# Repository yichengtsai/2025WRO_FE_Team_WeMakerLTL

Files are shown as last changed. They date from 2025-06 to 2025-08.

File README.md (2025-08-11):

# WRO 2025 未來工程師 - WeMaker-LTL

## 隊伍資訊

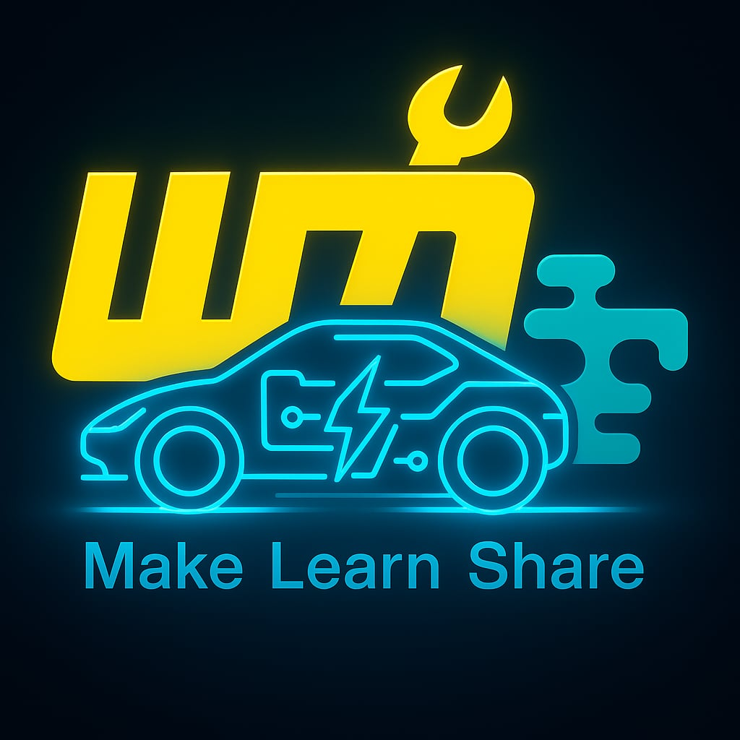
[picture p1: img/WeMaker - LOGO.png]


- **隊伍名稱**： WeMaker-LTL
- **隊員**： 蔡宜成、林仲斌、賴孟承
- **教練**： 楊智仁
- **學校/組織**： TCIVS WeMaker FabLab

## 評分對照表
為方便 WRO 2025 評審快速找到對應文件，以下為附件 C 的 7 項評分標準與相關檔案的對照表：
1. 移動性管理: [/docs/engineering_report.md](docs/engineering_report.md#移動性管理)
2. 電源和感測器:[/docs/engineering_report.md](docs/engineering_report.md#電源管理與感測)
3. 障礙物管理:[/docs/engineering_report.md](docs/engineering_report.md#障礙管理)
4. 圖片-團隊和汽車: [/media/README.md](media/README.md)
5. 完整的影片: [/media/README.md#demonstration-videos](media/README.md#demonstration-videos)
6. 使用GitHub: [/README.md](README.md)
7. 工程因素/技術條件: [/hardware/part_files](/hardware/part_files.md)
8. 評審總體印象: [/README.md/快速開始](README.md#快速開始)

## 快速開始
以下步驟幫助您快速設置並重現我們的專案成果，適用於其他隊伍、開發者或感興趣的使用者。

### 先決條件
- **硬體**：
  - Raspberry Pi 4B (8GB RAM)
  - JGA25-370 直流馬達 (x2) 與 L298N 馬達驅動模組
  - MG90 伺服馬達 (轉向)
  - TCS34725 顏色感測器
  - IMX477 攝影機模組
  - LDRobot D100 LiDAR
  - Adafruit BNO055 IMU
  - 底盤：雷射切割木板、3D 列印支架、LEGO 差速器與輪胎
- **工具**：雷射切割機、3D 印表機、螺絲起子、焊接工具
- **軟體**：Raspberry Pi OS、Python 3、Git、OpenCV、ROS

### 設置步驟
1. **組裝硬體**：
   - 參考 `hardware/circuit.md` 連接電路。
   - 使用 `docs/hardware` 中的 STL 檔案列印感測器與馬達支架。
   - 組裝底盤，確保阿克曼轉向系統（80% 阿克曼率）正確設置。
2. **設置軟體環境**：

   ```bash
   # Clone this repository
   git clone https://github.com/yichengtsai/2025WRO_FE_Team_WeMakerLTL.git
   cd WRO-2025-Future-Engineers-TeamName

   # Copy the image file to the SD card
   Use balenaEtcher copy the operating system to the SD card.
   Link: https://etcher.balena.io/
   ```
3. **配置參數**：
   - 檢查 `src/config/hardware_config.md` 中的硬體引腳與感測器設定，根據您的硬體調整。
4. **執行程式**：
   ```bash
   python src/test.py
   ```
   - 確保 Raspberry Pi 已連接到所有設備。
   - 將機器人放置於場地內，觀察其移動表現。
5. **驗證結果**：
   - 運行 `src/OpenChallenge.py` 與 `src/ObstacleChallenge.py` 檢查模組功能。
   - 參考 [media/README.md Demonstration Videos](media/README.md#demonstration-videos) 對比您的機器人表現。

### 預期成果
- 機器人應能自主在比賽場地內繞行三圈後停止，平均完成時間 60 秒。
- 機器人從停車區域出發，繞行三圈後自組移動到停車區域內，並且平行停進停車格內，平均完成時間 120 秒。

如需詳細說明，請參閱 `docs/engineering_report.md`。

## 硬體架構
- **主控制器**：Raspberry Pi 4B (8GB RAM)，負責處理感測器數據與執行導航演算法。
- **驅動馬達**：JGA25-370 直流馬達，提供差速驅動動力。
- **馬達驅動模組**：L298N，控制 JGA25-370 馬達的速度與方向。
- **轉向馬達**：MG90 伺服馬達，實現精確的阿克曼轉向控制（80% 阿克曼率）。
- **顏色感測器**：TCS34725，用於檢測賽道標記與顏色變化。
- **影像模組**：IMX477 高解析度攝影機，支援視覺導航與障礙辨識。
- **光達**：LDRobot D100 LiDAR，提供 360° 環境掃描與距離測量。
- **慣性測量單元 (IMU)**：Adafruit BNO055，追蹤機器人姿態與方向。
- **底盤**：雷射切割木板搭配 3D 列印支架，結合 LEGO 差速器與輪胎，確保結構穩固與靈活移動。
- **轉向系統**：阿克曼轉向系統（80% 阿克曼率），優化賽道轉彎性能。

詳細硬體設計請參閱 `/hardware/` 中的電路圖、照片與 3D 模型。

## 軟體架構
- **程式語言**：Python 3.8+，運行於 Raspberry Pi 4B。
- **模組化設計**：
  - **感測器與執行器模組** (`src/function.py`)：處理 TCS34725、LDRobot D100、BNO055的數據以及控制JGA25-370 馬達、L298N 驅動器 與 MG90 伺服馬達。
- **核心演算法**：
  - **路徑規劃**：在閃避積木的應用中，是根據積木在影像中的位置，計算出適當的轉向角度，並傳送至伺服馬達控制避開動作。該策略不使用傳統意義上的全區域規劃演算法，而是根據即時畫面中的積木位置做出本地性的轉向調整。
  - **障礙迴避**：為了讓車輛能順利繞過紅色與綠色積木，我們設計了一套簡單有效的閃避方法。當攝影機偵測到畫面中出現積木時，系統會判斷它的位置和面積，確認是否需要進行閃避動作。
  然後會根據積木的偏移程度和遠近調整轉向角度，並將這個角度轉換成伺服馬達的控制指令，讓車子能及時且順暢地避開障礙物。
  - **賽道辨識**：在場地中，地面設有藍色與橘色的標線作為定位依據。由於這兩條線間距接近，當顏色感測器偵測到任何一條時，通常代表車輛已進入彎道區域。
  為確保車輛能順利通過彎道，除了顏色判斷外，我們同步結合陀螺儀的角度資訊，控制車輛轉向的程度與穩定性。當進入轉彎時，系統會根據目前的角度進行角度補償與動作調整，並控制車輛以預定角度平滑轉彎，避免偏離路徑。

- **ROS 系統應用（LiDAR 專用）** :

   - 在本專案中，ROS 僅用於處理 LDRobot D100 LiDAR 的資料，其他感測器與控制則直接由 Python 模組處理。使用 ROS (Robot Operating System) 作為 LiDAR 資料的中介層，原因是 ROS 擁有豐富的感測器驅動支援，能快速整合 LDRobot D100 LiDAR。

   - **啟動方式**：透過 ROS 套件 ldlidar 啟動 LiDAR 節-點。

   - **資料流**：LiDAR 節點以 /scan topic 發布雷射掃描數據，Python 主控程式透過 rospy 訂閱該 topic 並進行距離與角度分析。

   - **用途**：用於比賽中的車道置中與障礙物偵測，提升機器人在動態環境中的反應速度。

詳見 `src/` 中的程式碼與模組說明。

## 儲存庫結構
- **docs/**：
  - `engineering_report.md`:完整的工程報告，涵蓋設計、開發與測試。
  - `testing.md`:測試計劃、結果與影片，展示機器人性能。
- **hardware/**：
  - `part_files.md`:硬體圖檔說明。
  - `circuit.md`:電路圖說明。
- **src/**：
  - `ObstacleChallenge.py`:障礙挑戰賽程式碼，執行避障、影像辨識、...。
  - `OpenChallenge.py`:資格賽程式碼，執行光達車輛置中，...。
  - `test.py`:單元測試程式碼，執行車輛周邊設備掃描與驗證設備正常工作。
- **requirements.txt**: Python依賴項清單。
- **LICENSE**:專案授權(MIT)。
- **CHANGELOG.md**:記錄專案更新的重大變更日誌。

## 安裝與執行
### 環境設置
1. **硬體準備**：
   - 確保所有硬體（Raspberry Pi 4B、JGA25-370、L298N 等）正確連接，參考 `/hardware/Circuit.md`。
   - 安裝 3D 列印零件，參考 `/hardware/part_files`。
2. **軟體環境**：
   ```bash
   # 複製儲存庫
   git clone https://github.com/yichengtsai/2025WRO_FE_Team_WeMakerLTL.git

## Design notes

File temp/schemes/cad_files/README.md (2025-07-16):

## CAD Files
* You can download or use these 2D/3D files by yourself. (For teaching purposes only)

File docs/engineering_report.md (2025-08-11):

# Engineering Report

# 移動性管理

## 底盤

### 驅動系統

### 馬達控制板
#### L298N
- IC 型號	L298N 雙 H 橋馬達驅動 IC
- 驅動電壓	5V ~ 35V（邏輯電壓 5V）
- 邏輯電壓	5V（模組可內建穩壓器）
- 最大輸出電流	2A / 每通道（瞬間最大可達 3A）
- 驅動通道數	2 通道（可驅動兩個直流馬達或一個雙極步進馬達）
- 控制方式	數位訊號控制（IN1 ~ IN4）、PWM 調速
- 支援功能	正轉、反轉、剎車、停止、PWM 調速
- 功耗	依負載與驅動電壓而異
- 模組接腳說明：
    - 接腳	功能
    - IN1 / IN2	控制馬達A方向
    - IN3 / IN4	控制馬達B方向
    - ENA / ENB	啟用並調速（通常接 PWM）
    - OUT1 / OUT2	馬達A輸出
    - OUT3 / OUT4	馬達B輸出
    - VCC	馬達電源（5V ~ 35V）
    - GND	接地
    - 5V	模組內部邏輯電壓輸出/輸入（若使用板上穩壓器，插跳線帽以供應5V）
<div align="center">
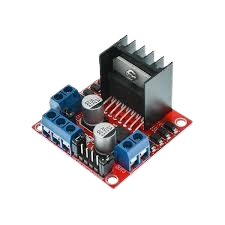
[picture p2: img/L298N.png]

</div>

#### 後輪直流馬達

在後輪驅動部分使用一顆130RPM 的直流馬達（DC Motor）作為動力來源。直流馬達具有轉速穩定、控制方式簡單的特性。本系統透過金屬齒輪組將馬達輸出連接至變速器，以調整扭力與轉速的傳遞效率，使車輛具備良好的啟動能力與穩定的行進速度。金屬齒輪具有良好的強度與耐磨性，可提升整體傳動系統的壽命與可靠度。

- 優點
  - 控制簡單，可透過 PWM 輕鬆調整速度
  - 可提供穩定扭力，適合驅動車輪
  - 搭配金屬齒輪與變速機構，提升扭力輸出並延長使用壽命
  - 兼具穩定推進與反應速度

<div align="center">
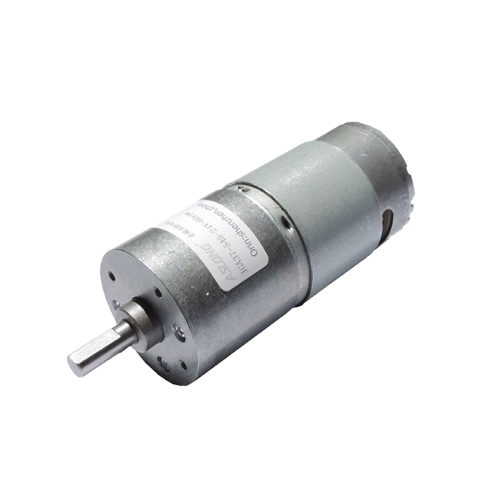
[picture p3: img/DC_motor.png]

</div>

#### 變速機構

我們考慮使用差速器結構作為後輪驅動的變速機構之一。差速器是一種可以同時傳遞動力與允許左右車輪轉速不同的機構，常用於汽車後輪驅動系統中。當車輛直線行駛時，兩側輪子等速旋轉；當轉彎時，內外側輪子轉速不同，差速器內部的行星齒輪則會自動補償兩側轉速差，維持動力平衡並減少輪胎摩擦。

圖 1（左圖）| 展示車輛直行時的差速器狀態，左右輪轉速一致，綠色中間齒輪不轉。

圖 2（右圖）| 展示車輛轉彎時的狀態，一側輪子轉速下降，差速器內部齒輪開始旋轉來補償另一側輪子的加速。

<p align="center">
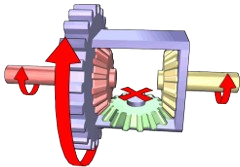
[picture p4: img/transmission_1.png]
圖1
  
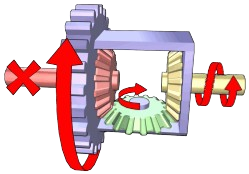
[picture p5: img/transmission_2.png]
圖2
  
</p>
<p align="center"><b>圖 1（左）：直行狀態  圖 2（右）：轉彎補償</b></p>

<div align="center">
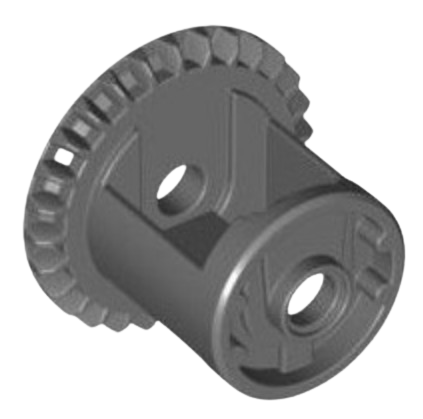
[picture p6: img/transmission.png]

</div>
<div align="center">樂高變速器</div>

### 轉向系統
#### Ackermann Steering Mechanism (阿克曼轉向機構介紹)

本設計採用了 **阿克曼轉向機構（Ackermann Steering Mechanism）** 作為前輪轉向方案。該機構透過幾何設計，使車輛在轉彎時前輪能指向同一圓心，內外輪轉向角度不同，符合理想轉彎軌跡。這種設計常見於真實汽車中，能有效提升轉彎穩定性與轉向效率。本車輛的阿克曼機構由光固化3D列印製作，搭配伺服馬達驅動，實現準確且穩定的轉向控制。
- 優點
  - 減少輪胎在轉彎時的滑移與磨損
  - 提高轉彎的穩定性與效率
  - 模擬真實車輛的轉向行為，提升真實感與控制精度
  - 可與伺服馬達整合，實現精準轉角控制

<div align="center">
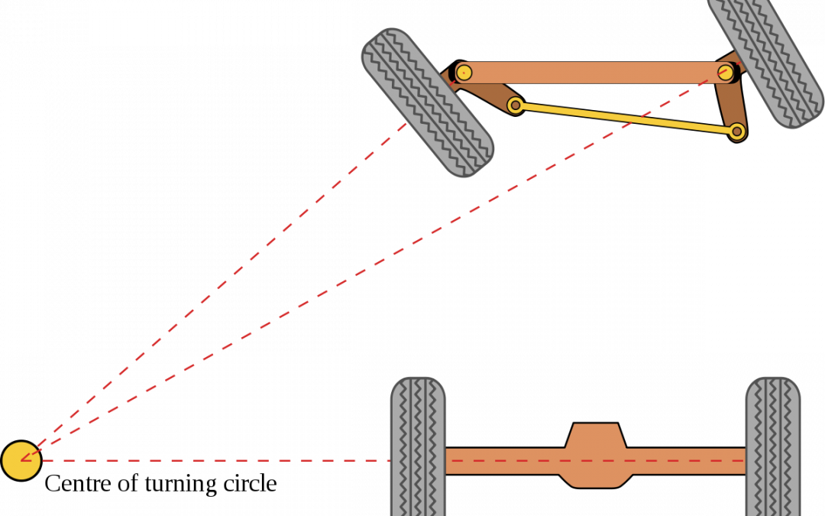
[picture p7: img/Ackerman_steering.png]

</div>
<div align="center">阿克曼轉向機構</div>

### 伺服馬達
#### MG90
- 工作電壓	4.8 V ～ 6.0 V
- 扭力	約 1.8 kg·cm（4.8 V）
約 2.2 kg·cm（6.0 V）
- 速度	約 0.1 秒 / 60°（4.8 V）
- 工作電流	空載約 100 mA，負載時更高
- 控制方式	PWM 控制，頻率約 50 Hz
- 齒輪材質	金屬齒輪（鋼齒）
- 軸承類型	雙軸承設計，提高穩定性
- 角度範圍	約 180°
<div align="center">
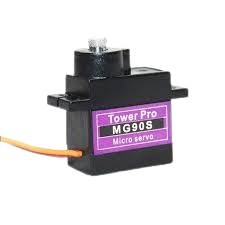
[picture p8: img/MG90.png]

</div>

# 電源管理與感測

## 電源(電池、降壓、每個模組供電方式)

### 電源系統概要圖
<div style="text-align: center;">
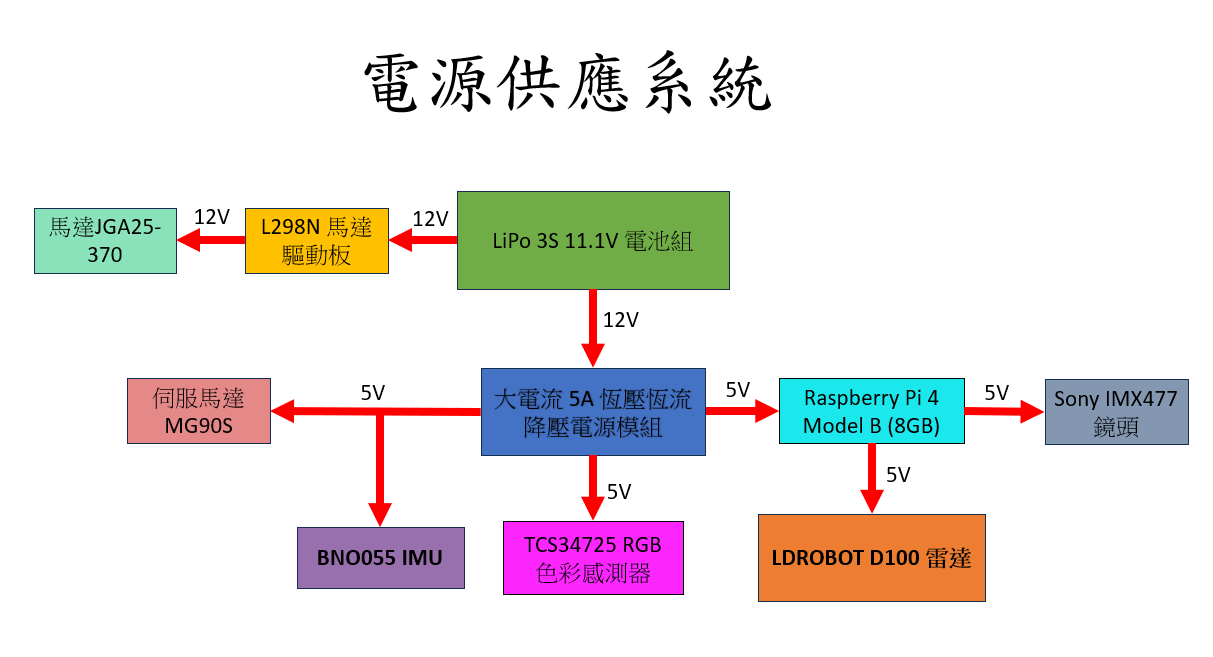
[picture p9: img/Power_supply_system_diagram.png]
電源供應系統
    
</div>

### 電池
原先我們採用 18650 鋰電池 作為電源供應，但由於樹莓派運作時需要穩定的 5V 電壓，而單顆 18650 電池的電壓範圍介於 4.2V 至 3.0V，即使透過升壓模組轉換，當電量下降過快時仍容易導致 電壓不穩，進而產生 系統重啟、螢幕閃爍，甚至在寫入過程中造成 SD 卡損壞 等問題。

為了解決上述問題，我們改採 LiPo 3S 11.1V 鋰聚合物電池 作為主要電源。雖然需要額外配置降壓模組來將電壓轉為穩定的 5V，但相較於單顆 18650 電池，其具有 更高的輸入電壓裕度與更穩定的電流輸出，能有效改善電壓不穩所帶來的風險，並提升系統運行的可靠性與安全性。

<div style="text-align: center;">
  <table>
    <tr>
      <th style="text-align: center;">18650充電電池</th>
      <th style="text-align: center;">LiPo 3S 11.1V 鋰聚合物電池</th>
    </tr>
    <tr>
      <td>
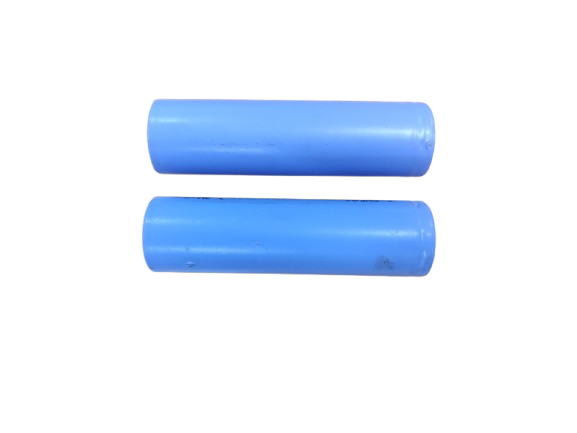
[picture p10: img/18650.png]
18650充電電池
        
      </td>
      <td>
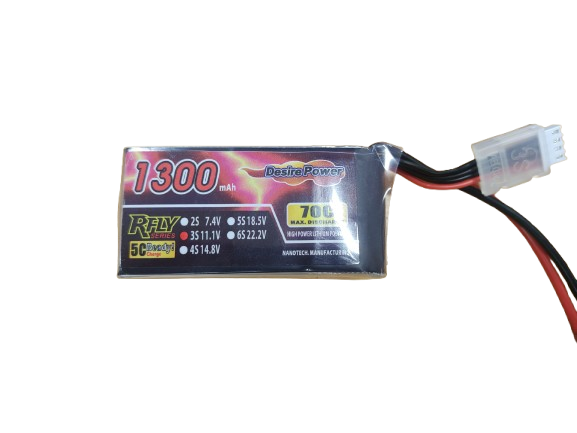
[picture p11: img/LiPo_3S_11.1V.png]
LiPo 3S 11.1V 鋰聚合物電池
        
      </td>
    </tr>
  </table>
</div>

### 降壓板
#### High Current 5A Constant Voltage Constant Current Buck Power Supply Module
- 輸入電壓	DC 4V ～ 38V（推薦 5V～36V）
- 輸出電壓	DC 1.25V ～ 36V（可調）
- 輸出電流	最大 5A（建議持續 4.5A 以下）
- 輸出功率	最大 75W（需加散熱片）
- 轉換效率	高達 96%（視輸入/輸出電壓與電流）
- 恆壓/恆流控制	可透過兩顆可調電位器分別設定輸出電壓與限流值
- 開關頻率	約 180kHz（視版本與晶片而定）
- 保護功能	輸出短路保護、過溫保護、過電流保護
<div align="center">
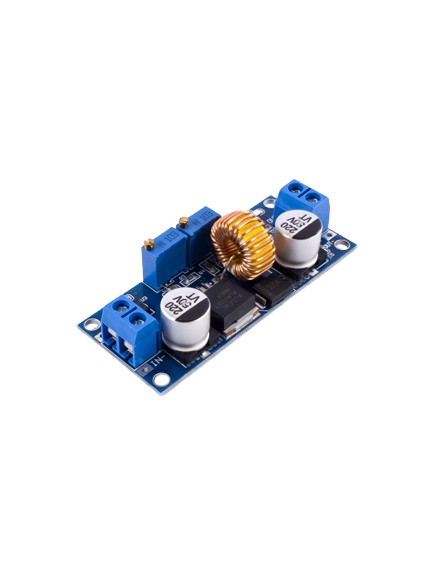
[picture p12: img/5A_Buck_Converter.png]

</div>

## 控制器
#### Raspbrry pi 4(8GB)
- 處理器 (CPU)
    - Broadcom BCM2711
    - 四核心 ARM Cortex-A72 (ARM v8) 64-bit 處理器
    - 時脈：1.5GHz
- 記憶體 (RAM)
    - 8GB LPDDR4 SDRAM
    - 記憶體與 SoC 整合在一個封裝上
- 圖形處理器 (GPU)
    - Broadcom VideoCore VI
    - 支援 OpenGL ES 3.0
- 輸出入埠 (I/O Ports)
    - 2 × USB 3.0
    - 2 × USB 2.0
    - 1 × Gigabit Ethernet (RJ45)
    - 40-pin GPIO header
    - CSI 相機介面
    - DSI 顯示介面
<div align="center">
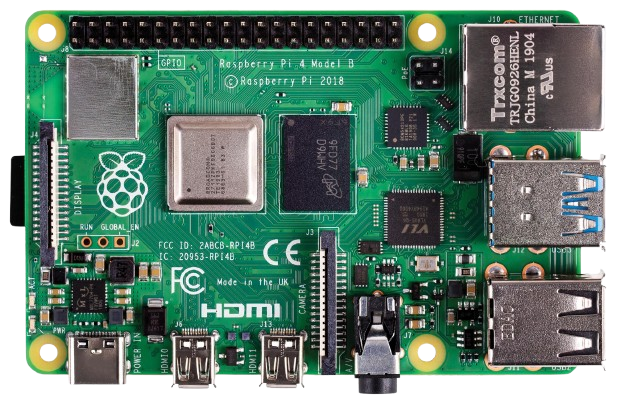
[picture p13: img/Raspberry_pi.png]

</div>

## 感測器
### 攝影鏡頭
#### Sony IMX477
- 感測器類型：CMOS（背照式，BSI）
- 解析度：12.3 Megapixels
- 感測器尺寸：1/2.3 英吋
- 像素大小：1.55μm × 1.55μm
- 有效畫素：4056 × 3040
- 輸出格式：
    - RAW Bayer（10-bit / 12-bit）
    - 支援 MIPI CSI-2 數位輸出
<div align="center">
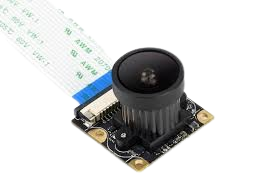
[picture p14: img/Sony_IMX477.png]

</div>

### 顏色感測器
#### TCS34725
- 感測元件類型RGB + Clear 光感測器
- 通訊介面I²C（最大 400 kHz）
- ADC 解析度16 位元（4 通道同步）
- 光感通道R（紅）、G（綠）、B（藍）、C（清光）
- 增益設定1x、4x、16x、60x
- 整合時間2.4 ms ~ 700 ms（可程式化）
- 紅外線濾光片內建，可提升色彩準確度
- 工作電壓2.7V ~ 3.6V（模組通常支援 3.3V / 5V）
- 輸出資料格式每通道 16 位元數值（R、G、B、C）
<div align="center">
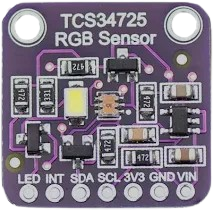
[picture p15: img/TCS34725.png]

</div>

### 光學雷達
#### LDROBOT D100 LiDAR
- 測距原理	Triangulation（CCD 三角測量）
- 掃描範圍	360° 全方位旋轉
- 測距範圍	0.15 ～ 8 公尺
- 角度解析度	約 1°
- 資料輸出頻率	約 2300 點/秒
- 掃描頻率	6 Hz（固定）
- 測距精度	±3 cm（典型值）
- 通訊介面	UART（3.3V TTL）
- 供電電壓	DC 5V（USB 或 UART）
<div align="center">
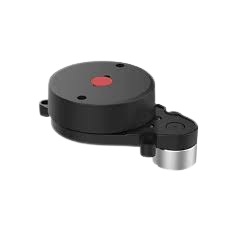
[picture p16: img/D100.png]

</div>

### 陀螺儀
#### BNO055 IMU
- 感測器內容	三軸加速度計 + 三軸陀螺儀 + 三軸磁力計 + 32-bit Cortex-M0F FUSION MCU
- 輸出數據	Quaternion（四元數）、Euler 角（Yaw, Pitch, Roll）、加速度、角速度、磁場、線性加速度、重力向量等
- 加速度範圍	±2g / ±4g / ±8g / ±16g
- 陀螺儀範圍	±125 / ±250 / ±500 / ±1000 / ±2000 dps
- 磁力計範圍	±1300 μT（X/Y 軸）、±2500 μT（Z 軸）
- 取樣率（輸出率）	最多 100 Hz（視模式）
- 絕對方向誤差	約 ±2.5°（典型值）
- 電壓需求	3.0V ~ 3.6V（模組常含穩壓可支援 3.3V / 5V）
- 通訊介面	I²C（100kHz～400kHz）與 UART（最大460800 bps）
- 內建演算法	Bosch Sensor Fusion Algorithm（可直接輸出姿態角）
<div align="center">
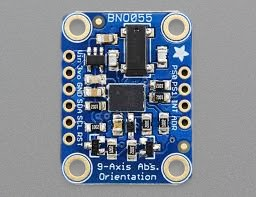
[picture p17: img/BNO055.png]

</div>

# 障礙管理

## 資格賽

### 功能概述
我們透過整合陀螺儀與光達，實現車子在限定空間內的繞圈移動行為。整體動作流程分為以下步驟：

一、初始化階段
啟動系統後，進行感測器初始化與通訊設定，同步讀取陀螺儀、光達與光感的資料，並透過光達資料進行初始位置的置中校正。

二、前進與距離判斷
車子向前行駛，光達持續檢測前方牆壁距離，當偵測到接近指定距離時，觸發轉彎程序。

三、轉彎動作
根據當前角度與預設目標角度，控制車子執行陀螺儀角度旋轉。旋轉完成後，再次透過光達執行橫向置中校正。

四、重複流程
校正完成後進入下一段直行流程，如此循環構成完整繞圈動作。

<div align="center">
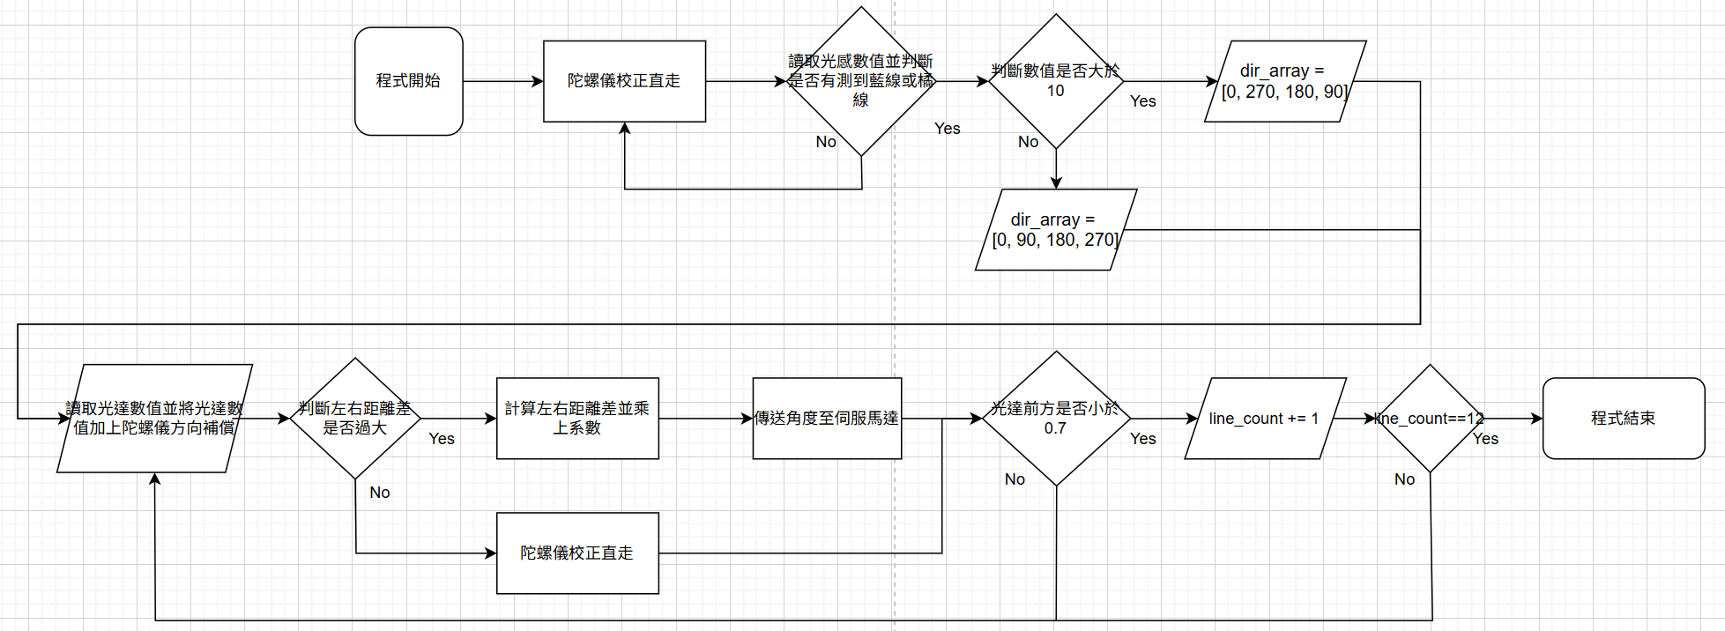
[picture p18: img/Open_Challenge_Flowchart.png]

</div>

### 光達置中校正運算

#### 補償原理:

一、角度轉換與投影修正

假設車身偏轉角度為 gyro（單位：度），轉換為弧度後，將原始距離乘上 cos(gyro)，修正光達讀值的投影誤差。
原因在於：當車身偏轉時，光達實際測得的是與牆面夾角方向的距離，其垂直距離需透過餘弦關係還原。

公式：
```
corrected_left  = left  × cos(gyro)
corrected_right = right × cos(gyro)
```
二、額外補償微調（角度漂移影響）

為進一步提升精度，對左右距離加入一項與角度成比例的補償量 angle_compensation = abs(gyro) × 0.005，模擬由於傾斜造成的視角偏移。

根據偏轉方向，左右距離分別加減該補償量：
```
if gyro > 0:
    corrected_left  -= angle_compensation
    corrected_right += angle_compensation
else if gyro < 0:
    corrected_left  += angle_compensation
    corrected_right -= angle_compensation
```

## 障礙挑戰賽

### 功能概述

本系統為一套即時影像與感測器融合的避障控制機制，主要針對車子在移動過程中自動偵測前方障礙物（牆體與積木），並根據當前車身姿態動態調整避讓路徑。系統透過攝影機進行目標輪廓偵測，獲取障礙物位置，並結合陀螺儀輸出的車身旋轉角度進行座標補償，以修正因鏡頭畸變與車身姿態變化造成的誤差。
在避障邏輯中，系統會先根據車頭與目標物位置計算斜率，映射為伺服馬達轉向角度，生成基礎避讓方向；同時，系統會預測此路徑是否可能與牆體相交，若偵測到潛在碰撞，則計算交點位置並動態修正避讓方向，確保車輛在保持安全距離的前提下順利繞過障礙物。

<div align="center">
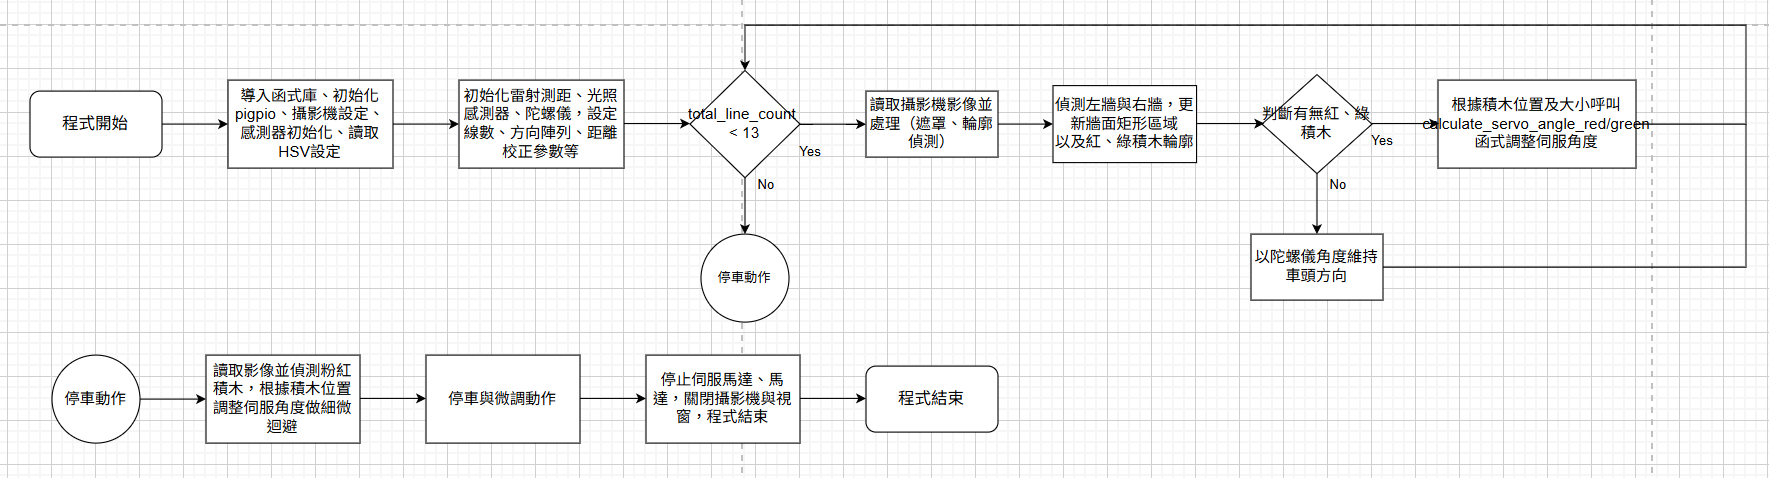
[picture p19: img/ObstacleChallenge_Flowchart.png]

</div>

### 顏色遮罩設定與輪廓擷取

為了辨識場地中的紅色與綠色積木，程式採用了 HSV 色彩空間來進行顏色篩選。與 RGB 不同，HSV 更適合處理顏色辨識的問題，因為它將顏色（Hue）、飽和度（Saturation）與明亮度（Value）分離，能更穩定地適應不同光照條件。

<div align="center">
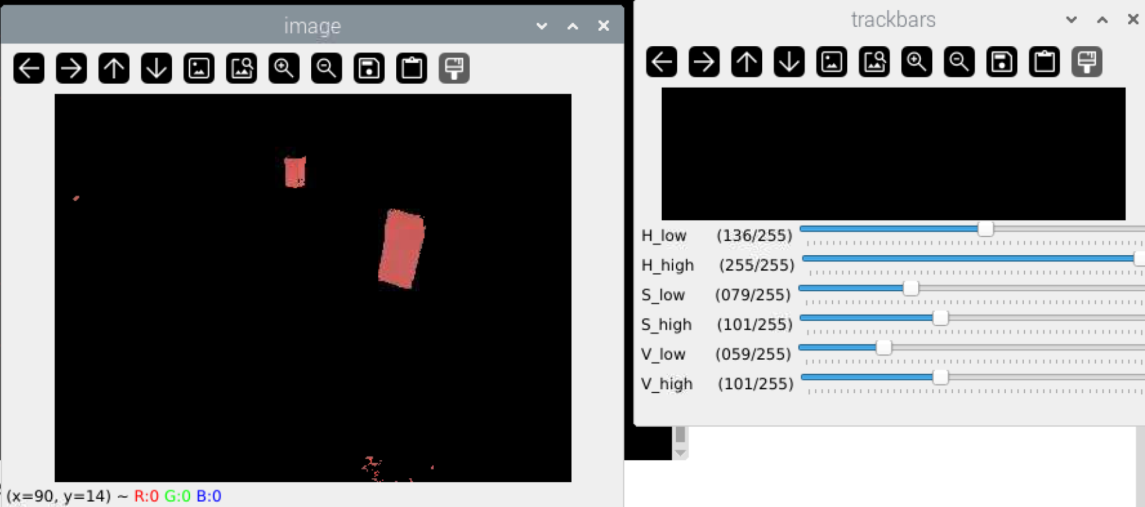
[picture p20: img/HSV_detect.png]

</div>

使用 ``` cv2.inRange ``` 函式可以將在範圍內的像素轉為白色（255），不在範圍內的轉為黑色（0），形成二值遮罩。再透過 cv2.findContours 找出輪廓，即可擷取紅綠積木在影像中的位置。這些輪廓後續會用來判斷積木位置與大小，進一步進行避障判斷與行為控制。

根據設定好的色彩範圍，對畫面進行遮罩，找出特定顏色積木的區域
```
green_mask = cv2.inRange(hsv, green_lower, green_upper)
contours, _ = cv2.findContours(green_mask, cv2.RETR_EXTERNAL, cv2.CHAIN_APPROX_SIMPLE)
```

### 物件偵測及位置取得

系統透過影像處理（OpenCV）對畫面中的紅色牆或積木進行輪廓偵測。
為了後續避障，需要獲取該物件的矩形邊界座標 (x, y, w, h) 及其底部 y 座標 y_bottom，並找出距離車輛最近的目標。
```
for cnt in red_contours:
    area = cv2.contourArea(cnt)
    if area > 50:
        x, y, w, h = cv2.boundingRect(cnt)
        cv2.rectangle(imageFrame, (x, y), (x + w, y + h), (0, 0, 255), 2)
         y_bottom = y + h
        if y_bottom > max_y_bottom_red:
            max_y_bottom_red = y_bottom
            closest_tx_red = x + w + 100 + int(abs(gyro)*0.15)
            closest_ty_red = y
```

### 陀螺儀補償

由於攝影機鏡頭存在一定的畸變（廣角或桶狀變形），車輛在旋轉時，物體的投影位置會產生偏移，導致直接從影像計算的避障角度不準確。
為修正此誤差，將車輛的實際旋轉角度（由陀螺儀讀取）乘以一個比例係數，動態調整積木的 x 座標位置，達到補償效果。
```
closest_tx_red = x + w + 100 + int(abs(gyro)*0.15)
```

### 避障路徑計算

避障的基礎邏輯是根據車頭位置 (cx, cy) 與目標物位置 (bx, by) 計算斜率 m = dy / dx，再透過映射函數（mapping）將斜率轉換為伺服馬達的轉向角度。
此步驟處理「正常閃避路徑」，在沒有撞牆風險時直接執行。
```
dx = abs(bx - cx)
dy = abs(by - cy)
m = dy/dx
m = constrain(m, 0, 3)
servo_angle = mapping(m, 0, 3, 50, 10) 
servo.angle(servo_angle)
```

### 牆體碰撞檢測與路徑修正

為避免閃避過程中撞到牆，畫面會在多繪製一條斜線代表車身預計經過的避障路徑，並透過 ```cv2.clipLine``` 判斷此路徑是否與牆的矩形邊界相交。
若相交，計算交點最大 x 座標與牆右邊界的距離差 diff，並依車頭與積木相對位置（象限）調整原始 dx_raw，再重新計算修正後的斜率與伺服角度。

<div align="center">
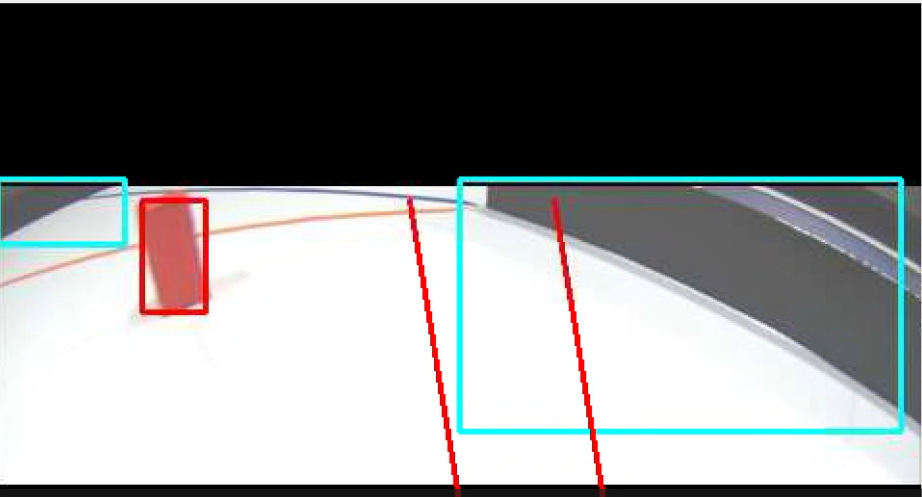
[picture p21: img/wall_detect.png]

</div>

判斷斜線與矩形是否重疊，並輸出斜線經過矩形的兩點
```
intersects, clipped_pt1, clipped_pt2 = cv2.clipLine(rect_red, (315, cy), (bx+75, by))
```
計算x位置校正後斜率及依照象限調整伺服馬達角度
```
x_man_overlap = max(clipped_pt1[0], clipped_pt2[0])
rect_right_x = rect_red[0]
diff = x_man_overlap - rect_right_x
if dx_raw > 0:
    dx_adjusted = dx_raw - diff - 22  # 第一象限處理
else:
    dx_adjusted = dx_raw + diff - 22  # 第二象限處理
if abs(dx_adjusted) < 1e-5:
    dx_adjusted = 1e-5 if dx_adjusted >= 0 else -1e-5
m = dy / dx_adjusted
m_abs = abs(m)
m_abs = constrain(m_abs, 0, 3)
if dx_adjusted > 0:
    servo_angle = mapping(m_abs, 0, 3, 50, 0)
    servo.angle(servo_angle) # 往右
else:
    servo_angle = mapping(m_abs, 0, 3, 30, 15)
    servo.angle(-servo_angle) # 往左
```

# 團隊營運

## 工作分配
| 姓名  | 負責項目 | 貢獻說明 |
| --- | --- | --- |
| 蔡宜成 | 軟體程式設計  | 撰寫 Raspberry Pi 控制程式，包括感測器資料讀取、影像處理、路徑規劃邏輯。 |
| 林仲斌 | 撰寫Github與硬體電路與整合 | 設計並焊接電路板（含感測器與電源模組接線），負責供電穩定與模組連裝。 |
| 賴孟承 | 撰寫Github與機構設計與製作 | 使用 Onshape 設計底盤與轉向系統零件，負責3D列印與組接。 |
## 

# 未來發展

### 1. 系統效能優化與智慧化
- **感測器融合演算法強化**

  - 由目前的幾何修正 + 基礎補償，提升為 EKF（Extended Kalman Filter） 或 UKF（Unscented Kalman Filter），在光達、IMU、攝影機資料融合時提高精度與抗雜訊能力。

  - 增加即時誤差估計（例如同時估算定位誤差、轉向精度）。

- **AI 視覺辨識**

  - 將 HSV 色彩遮罩升級為 深度學習物件檢測（YOLO、MobileNet-SSD），提升在不同光照與背景下的辨識準確率。

  - 透過邊緣運算（Raspberry Pi + Coral TPU）實現即時推論。

- **動態路徑規劃**

  - 從現有的避障邏輯，進一步實作 A*、D* Lite、RRT 等路徑規劃演算法，讓車輛能即時找出最佳路徑而非單純閃避。

### 2. 硬體與能源管理改進
- **高效率馬達驅動模組**

  - 改用 MOSFET 驅動 或 BLDC 無刷馬達，提高效率並減少發熱。

- **能源監控系統**

  - 增加電池管理系統（BMS） 與電壓/電流即時監控，讓控制程式可以根據剩餘電量自動調整車速或回充策略。

- **模組化底盤設計**

  - 將車體設計成可更換模組（不同輪距、不同驅動方式），方便實驗不同傳動與轉向機構。

### 3. 定位與地圖建構
- **SLAM（Simultaneous Localization and Mapping）**

  - 利用 LiDAR 與攝影機進行 2D 或 3D SLAM（例如 GMapping、Hector SLAM、ORB-SLAM2），讓車輛能在未知環境中自我定位與繪製地圖。

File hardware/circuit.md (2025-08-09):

## 電路板模組示意
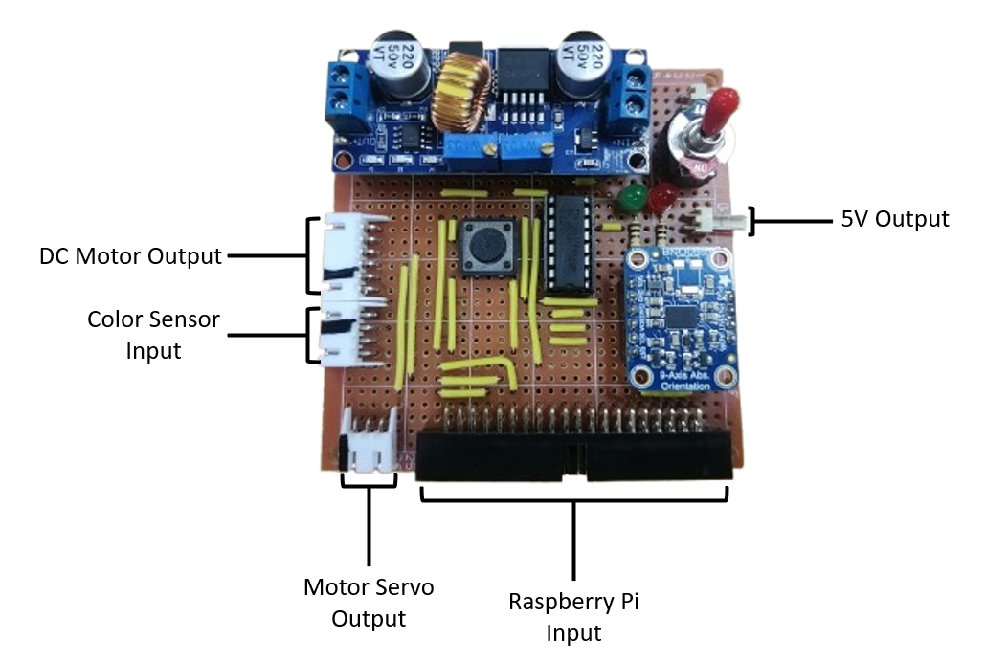
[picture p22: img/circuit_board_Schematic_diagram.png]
Hardware Module Board

如上圖所示，此電路板搭載多項功能模組：

- Raspberry Pi Input：與 Raspberry Pi 主控板連接的輸入端口。

- DC Motor Output：直流馬達的電源輸出接口。

- Motor Servo Output：伺服馬達控制信號輸出。

- Color Sensor Input：顏色感測器數據輸入端口。

- 5V Output：穩壓後的 5V 電源輸出，供應系統其他模組。
## Circuit Instruction
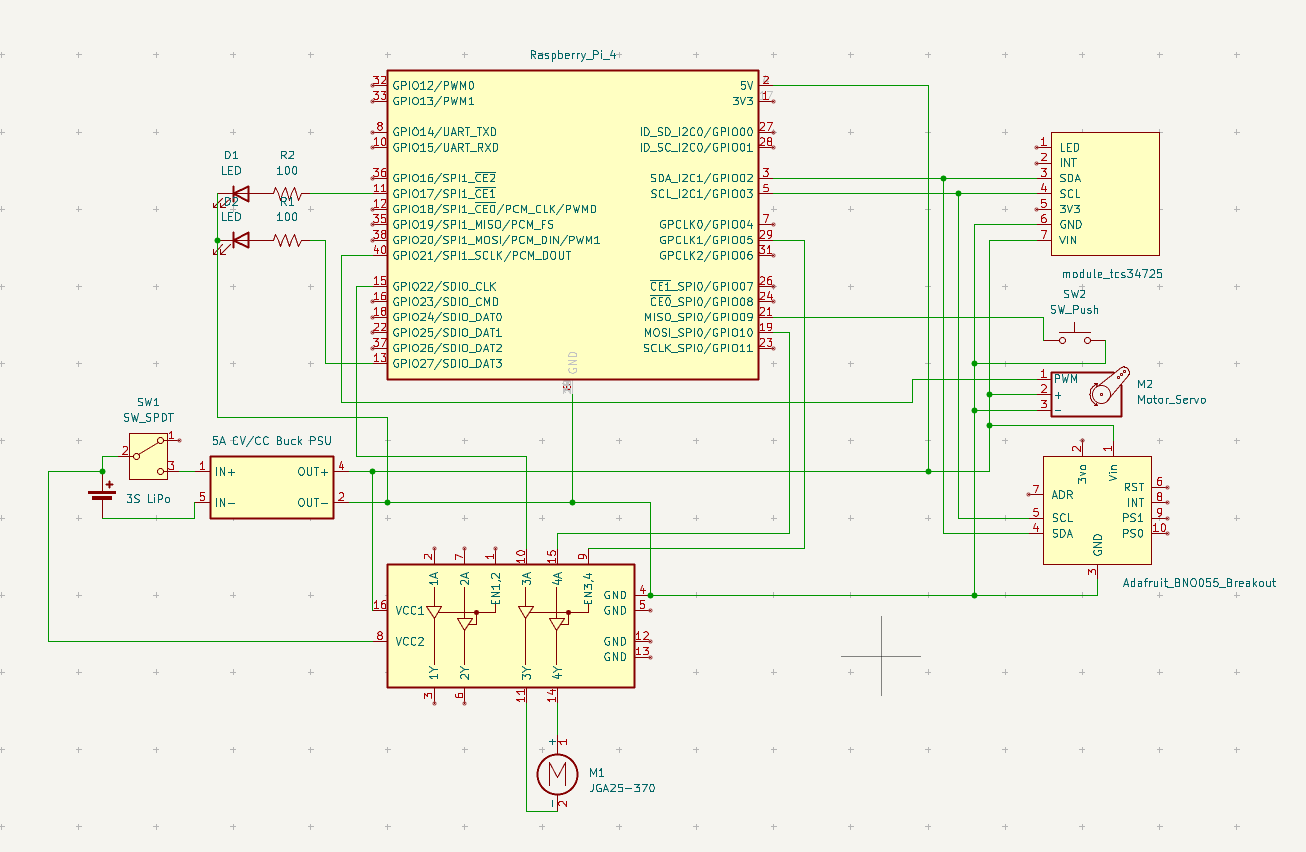
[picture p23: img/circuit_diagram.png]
System Circuit Diagram

本電路圖展示整體系統架構，核心控制單元為 Raspberry Pi 4，搭配多個模組包括直流馬達、伺服馬達、感測器及電源管理模組。以下為各模組詳細說明。

## 1. Raspberry Pi 4 主控板
- 作為系統中央控制單元，透過 GPIO 腳位對外連接並控制各周邊元件。

- 利用 I²C 通訊協定與 TCS34725 顏色感測器及 BNO055 姿態感測器進行資料交換。

- 控制 L298N 馬達驅動模組與伺服馬達動作。

- 使用 GPIO17 及 GPIO27 控制兩組 LED 指示燈。
W

## 2. 電源系統
### 3S LiPo 電池組 (標稱 11.1V)
- 作為系統主要電源來源。

- 配置 SPDT 開關（SW1）以實現主電源的開啟與關閉控制。

### 5A CV/CC 降壓穩壓電源模組 (Buck PSU)
- 將 3S LiPo 電池電壓穩定降至 5V，提供穩定電源給系統各模組。

- 供電對象包括 Raspberry Pi 4（5V, GND）、L298N 馬達驅動器、感測器模組（BNO055、TCS34725）及 LED 指示燈。

## 3. 馬達控制系統
### 直流馬達 (JGA25-370)
- 透過 L298N 雙向 H 橋馬達驅動模組控制。

- L298N 的 IN1、IN2 腳位分別連接 Raspberry Pi GPIO23 和 GPIO24，用以控制馬達旋轉方向。

- ENA 腳位目前直接接至 5V，代表馬達全速運轉；若需速度調控，建議接至 PWM 腳位並由軟體調節。

### 伺服馬達 (Motor_Servo)
- 使用 Raspberry Pi GPIO18 (物理腳位12) 輸出 PWM 控制訊號，實現角度定位。

## 4. 感測器模組
### TCS34725 顏色感測器
- 利用 I²C 通訊 (SDA: GPIO2, SCL: GPIO3) 與 Raspberry Pi 連接。

- 供電為 3.3V，確保感測器與 Pi 之間的邏輯電平相容。

- LED 控制腳及中斷腳 (INT) 目前未連接，表示未使用這些功能。

### BNO055 姿態感測器 (Adafruit_BNO055_Breakout)
- 同樣透過 I²C 介面 (SDA: GPIO2, SCL: GPIO3) 與 Raspberry Pi 通訊。

- 使用 5V 電源供電，模組內建穩壓器確保安全。

- RST、INT、PS0、PS1 腳位未接，工作於 I²C 基本模式。

## 5. LED 指示燈
- 兩顆 LED 分別接於 GPIO17 與 GPIO27。

- 每顆 LED 串聯 100Ω 限流電阻，以保護 LED 並控制電流。

## 6. 按鈕開關
- SW2 為推鈕開關，接於 GPIO22，作為程式啟動的觸發輸入。

- 建議於 GPIO22 設置適當的下拉電阻以避免浮動。

## 7. 系統總覽與接口對照
| 子系統 | 功能描述 | Raspberry Pi GPIO 腳位 | 備註 |
| --- | --- | --- | --- |
| Raspberry Pi 4 | 中央控制單元  | — | — |
| L298N + JGA25-370 | 直流馬達控制  | GPIO23 (IN1)、GPIO24 (IN2)、ENA 接 5V | 可改接 PWM 調速 |
| 伺服馬達 (Motor\_Servo) | 角度控制 | GPIO18 (PWM 輸出) | 硬體 PWM 支援 |
| TCS34725 | 顏色偵測 | I²C (GPIO2 SDA / GPIO3 SCL) | 3.3V 供電，無中斷 |
| BNO055 | 姿態偵測 | I²C (GPIO2 SDA / GPIO3 SCL) | 5V 供電，基本 I²C 模式 |
| LED 指示燈 x2 | 狀態顯示 | GPIO17、GPIO27 | 100Ω 限流電阻 |
| 按鈕開關 (SW2) | 使用者輸入觸發 | GPIO22 | 建議使用下拉電阻 |
| 電源系統 | 供電管理 | — | 3S LiPo 電池 + 降壓模組 |

## 8. 改善建議與注意事項
- 馬達速度控制：ENA 腳位建議改接 Raspberry Pi PWM 腳位，可軟體調整馬達轉速。

- I²C 上拉電阻：確認感測器模組板是否已含 4.7kΩ 上拉電阻，若無，建議在 SDA 與 SCL 加上合適上拉。

- 按鈕輸入：GPIO22 建議使用硬體或軟體下拉電阻以避免腳位浮動誤觸發。

- 電源安全：LiPo 電池須搭配適當保護電路，避免過放或過充風險。

- 線材與接頭：建議使用足夠線徑並加強接頭防護，避免高電流造成電壓降或接觸不良。

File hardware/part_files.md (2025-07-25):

# Part Files

## Chassis (Laser cutting)

您可根據下列 DXF 檔案進行雷射切割，以製作本設計所需的底盤與結構件。

* [Bottom](../hardware/DXF/Plate.DXF)
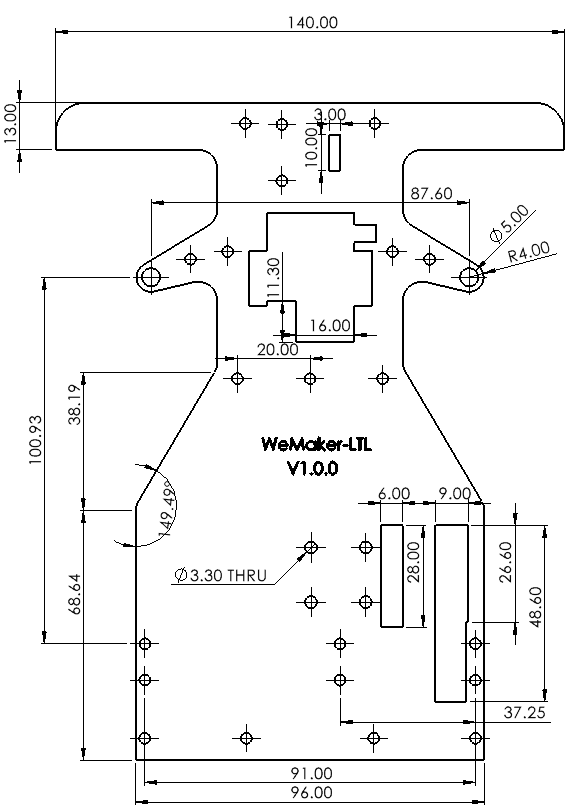
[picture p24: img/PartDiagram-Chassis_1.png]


* [Middle](../hardware/DXF/Plate_2.DXF)
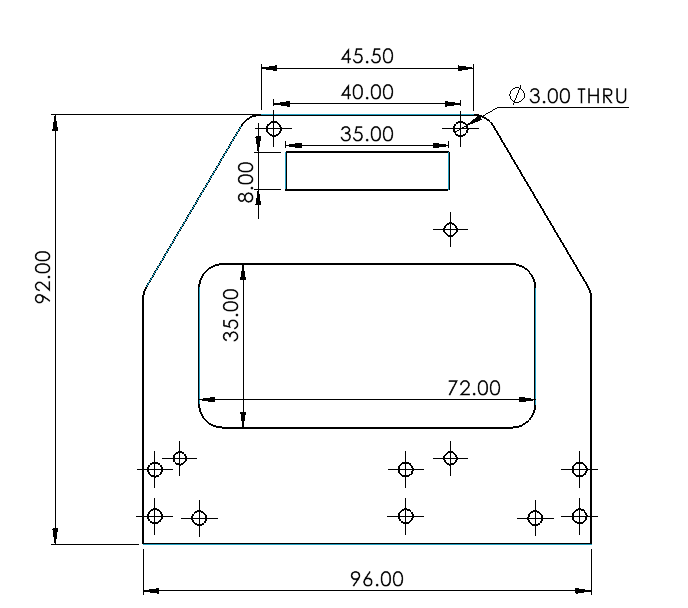
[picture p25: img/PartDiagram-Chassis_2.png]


* [Top](../hardware/DXF/Plate_3.DXF)


## Bracket (3D Printing)
透過下列提供的檔案，您可使用光固化 3D 列印方式製作零件，組裝出與本機構相同的結構。

* [Bearing Bracket](../hardware/STL/Bearing%20Holder_1.STL)


* [Bearing Bracket](../hardware/STL/Steering%20Holdor-1-1.STL)


* [Steering Knucle](../hardware/STL/ST%20Knuckle-18.STL)


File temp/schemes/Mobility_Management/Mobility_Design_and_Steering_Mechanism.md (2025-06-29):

## <div align="center">Mobility Design and Steering Mechanism（移動設計與轉向機構）</div> 

### 前輪伺服馬達

前輪轉向機構使用了MG90S 金屬齒輪伺服馬達作為驅動元件。MG90S 是一款小型高扭力伺服馬達，具備金屬齒輪傳動結構，具有良好的耐用性與抗衝擊能力，特別適合應用於需要穩定轉向的自走車系統。透過 PWM 控制可精準設定角度，搭配阿克曼轉向機構可實現穩定且真實的車輛轉彎行為。

- 優點
  - 扭力充足，最大可達約 1.8 kg·cm（4.8V）
  - 金屬齒輪結構，耐磨損、壽命長，適合承受較大負載
  - 易於安裝到有限空間中
  - 反應靈敏、角度控制精確，適合轉向用途

<div align="center">

</div>

### 後輪直流馬達

在後輪驅動部分使用一顆620RPM 的直流馬達（DC Motor）作為動力來源。直流馬達具有轉速穩定、控制方式簡單的特性。本系統透過金屬齒輪組將馬達輸出連接至變速器，以調整扭力與轉速的傳遞效率，使車輛具備良好的啟動能力與穩定的行進速度。金屬齒輪具有良好的強度與耐磨性，可提升整體傳動系統的壽命與可靠度。

- 優點
  - 控制簡單，可透過 PWM 輕鬆調整速度
  - 可提供穩定扭力，適合驅動車輪
  - 搭配金屬齒輪與變速機構，提升扭力輸出並延長使用壽命
  - 兼具穩定推進與反應速度

<div align="center">

</div>

### Ackermann Steering Mechanism (阿克曼轉向機構介紹)

本設計採用了 **阿克曼轉向機構（Ackermann Steering Mechanism）** 作為前輪轉向方案。該機構透過幾何設計，使車輛在轉彎時前輪能指向同一圓心，內外輪轉向角度不同，符合理想轉彎軌跡。這種設計常見於真實汽車中，能有效提升轉彎穩定性與轉向效率。本車輛的阿克曼機構由光固化3D列印製作，搭配伺服馬達驅動，實現準確且穩定的轉向控制。
- 優點
  - 減少輪胎在轉彎時的滑移與磨損
  - 提高轉彎的穩定性與效率
  - 模擬真實車輛的轉向行為，提升真實感與控制精度
  - 可與伺服馬達整合，實現精準轉角控制

<div align="center">

</div>
<div align="center">阿克曼轉向機構</div>

### 變速機構

我們考慮使用差速器結構作為後輪驅動的變速機構之一。差速器是一種可以同時傳遞動力與允許左右車輪轉速不同的機構，常用於汽車後輪驅動系統中。當車輛直線行駛時，兩側輪子等速旋轉；當轉彎時，內外側輪子轉速不同，差速器內部的行星齒輪則會自動補償兩側轉速差，維持動力平衡並減少輪胎摩擦。

圖 1（左圖）| 展示車輛直行時的差速器狀態，左右輪轉速一致，綠色中間齒輪不轉。

圖 2（右圖）| 展示車輛轉彎時的狀態，一側輪子轉速下降，差速器內部齒輪開始旋轉來補償另一側輪子的加速。

<p align="center">
  圖1
  圖2
</p>
<p align="center"><b>圖 1（左）：直行狀態  圖 2（右）：轉彎補償</b></p>

<div align="center">

</div>
<div align="center">樂高變速器</div>

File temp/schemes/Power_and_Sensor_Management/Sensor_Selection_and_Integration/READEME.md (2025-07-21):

## <div align="center">攝影鏡頭</div> 
### Sony IMX477
- Sony IMX477 是一款高性能的 12.3 百萬畫素 CMOS 感光元件，專為需要高解析度與靈敏度的應用所設計。該感光元件廣泛應用於樹莓派相機模組（如 Raspberry Pi HQ Camera），支援更換鏡頭與手動對焦，提供使用者更大的彈性與專業級影像品質。

    IMX477 採用背照式（BSI）堆疊式感光技術，有效提升在低光環境下的表現，並支援高幀率（例如在 1080p 解析度下可達 60fps），適合用於機器視覺、影像處理、AI 辨識與光學實驗等應用。

#### 主要特色：
- 解析度：4056 × 3040（12.3MP）
- 感光元件尺寸：1/2.3 吋
- 像素大小：1.55 μm × 1.55 μm
- 接口：支援 MIPI CSI-2
- 支援更換 C / CS 接口鏡頭
- 相容樹莓派與其他開發平台

<div align="center">

</div>

## <div align="center">處理器</div>
### Raspberry Pi 4 Model B (8GB RAM)  
- Raspberry Pi 4 Model B 是樹莓派基金會推出的第四代單板電腦，具備更強大的效能與多元的應用彈性。其 8GB RAM 版本特別適合用於需要大量記憶體的應用場景，如桌面替代系統、伺服器模擬、AI 開發、資料處理與嵌入式視覺計算等。

    這款微型電腦配備四核心 ARM Cortex-A72 處理器（64-bit, 1.5GHz），搭載 USB 3.0、高速 Gigabit Ethernet、雙螢幕輸出（支援 4K 顯示）與雙頻 Wi-Fi，是一個體積小巧但功能完整的開發平台。
#### 主要特色：
- 處理器：Broadcom BCM2711, Quad core Cortex-A72 @ 1.5GHz
- 記憶體：8GB LPDDR4-3200 SDRAM
- 顯示輸出：2 個 micro-HDMI（最高支援雙 4K 顯示）
- USB：2 個 USB 3.0、2 個 USB 2.0
- 網路：Gigabit Ethernet、2.4GHz/5.0GHz 雙頻 Wi-Fi、Bluetooth 5.0
- 儲存：microSD 卡插槽（作業系統與資料儲存）
- GPIO：40-pin GPIO 排針，相容於先前版本
<div align="center">

</div>

## <div align="center">光學雷達</div>
### D100 LiDAR
- D100 LiDAR 是一款高性能、低成本的雷射測距感測器，專為中短距離距離量測與環境感知設計。其核心技術基於飛行時間（ToF, Time-of-Flight）原理，能精確地量測物體與感測器之間的距離，常見於機器人避障、地圖建構（SLAM）、無人載具導航與智慧設備中的應用。

    D100 通常搭載旋轉掃描模組，可實現 360 度的環境感測能力，並支援串列埠或 USB 介面與各類開發板（如 Raspberry Pi、Arduino、Jetson Nano）整合，便於開發者進行二次開發與應用部署。
#### 主要特色：
- 量測範圍：一般為 0.1 ～ 12 公尺（依型號而異）
- 精度：公分級距離解析度
- 掃描頻率：一般為 5～12Hz
- 視角：360 度旋轉式掃描（取決於模組設計）
- 通訊介面：USB / UART / CAN（依版本而異）
- 應用範圍：機器人導航、地圖建構、自主避障、室內定位、SLAM
<div align="center">

</div>

## <div align="center">降壓板</div> 
### High Current 5A Constant Voltage Constant Current Buck Power Supply Module
- 這款 5A 恆壓恆流降壓電源模組是一種高效能的 DC-DC 轉換器，能將較高的直流輸入電壓穩定地降至目標電壓，並可同時限制最大輸出電流，具備恆壓（CV）與恆流（CC）兩種工作模式，廣泛應用於鋰電池充電、LED 驅動、馬達控制與實驗室可調電源等場合。

    模組內建電位器可調整輸出電壓與限制電流，輸出端常搭配數位電壓/電流顯示器，方便即時監控。高效率轉換架構與多重保護機制，讓其在高功率應用中穩定可靠。

#### 主要特色：
- 輸入電壓範圍：一般為 6V～36V（依型號略有不同）
- 輸出電壓範圍：1.25V ～ 32V（可調）
- 最大輸出電流：5A（建議穩定使用在 4.5A 以下）
- 功率容量：最大約 75W～100W
- 轉換效率：高達 95%（視輸入/輸出電壓與負載而定）
- 具備：過溫保護、輸出短路保護、反接保護（部分版本）
- 控制方式：可調電壓與電流（雙電位器設計）
<div align="center">

</div>

## <div align="center">陀螺儀</div> 
### BNO055 IMU
- BNO055 是由 Bosch Sensortec 所推出的一款高整合度的九軸慣性測量單元（IMU），內建三軸加速度計、三軸陀螺儀與三軸磁力計，並結合 32 位元微控制器，能即時進行感測數據融合，直接輸出絕對方向資訊（如歐拉角或四元數），大幅降低使用者開發複雜度。

    與傳統 IMU 不同，BNO055 內建 Bosch 自家 Sensor Fusion 演算法，可自動處理感測數據漂移、磁場干擾與校正問題，適合應用於機器人導航、姿態控制、VR/AR、無人載具與運動追蹤等場景。
#### 主要特色：
- 整合三軸加速度計、陀螺儀、磁力計
- 內建 32 位元協同處理器，支援感測器融合演算法
- 輸出格式：歐拉角、四元數、加速度、角速度、磁場等
- 通訊介面：I²C 與 UART
- 低功耗設計，適合行動設備與長時間運作
- 感測範圍：
    * 加速度計：±2g / ±4g / ±8g / ±16g
    * 陀螺儀：±125 / ±250 / ±500 / ±1000 / ±2000 dps
    * 磁力計：±1300 µT（x, y 軸），±2500 µT（z 軸）
<div align="center">

</div>

## <div align="center">顏色感測器</div> 
### TCS34725
- TCS34725 是一款高精度的 RGB 與光度感測器，由 AMS（現為 ams OSRAM）開發，內建 4 個光感通道（紅、綠、藍、透明），能準確地測量環境中光線的顏色成分與亮度。感測器內部搭載紅外線阻隔濾光片，可提高色彩辨識準確性，特別適合用於顏色分類、光源校正、自走車路徑辨識、環境光調整等應用。

    TCS34725 內建 16 位元 ADC，支援 I²C 通訊介面，並搭配中斷功能與可控 LED 照明（在模組版本中），方便使用於各類平台如 Arduino、Raspberry Pi 與 STM32 等開發環境。

#### 主要特色：
- 色彩通道：紅色、綠色、藍色、透明（Clear）
- 解析度：16 位元 ADC，具備高靈敏度
- 通訊介面：I²C（7-bit 地址：0x29）
- 整合 IR 阻擋濾光片，提升色彩準確度
- 模組常附白光 LED，可提升低光環境的辨識能力
- 工作電壓：3.3V 或 5V（視模組而定）
<div align="center">

</div>

## <div align="center">馬達控制晶片</div> 
### L298N
- L298N 是一款常見的雙H橋馬達驅動模組，主要用於控制直流馬達與步進馬達的正反轉與速度調節。它基於 ST 公司推出的 L298N 晶片，可同時驅動兩個直流馬達，或一個雙極性步進馬達。

    模組可接受 5V 到 35V 的馬達電源輸入，並能提供最高約 2A 的輸出電流。透過 IN1~IN4 控制端搭配 PWM 訊號輸入，可靈活地控制馬達的啟動、停止、轉向與速度。
    常見應用包括：機器人底盤、小型自走車、自動門控制等。

#### 主要特色：
- 雙H橋設計，可獨立控制兩顆馬達
- 支援 PWM 調速
- 內建散熱片與5V 穩壓輸出（可選擇是否啟用）
- 適用於 Arduino、Raspberry Pi 等開發板
<div align="center">

</div>

## <div align="center">伺服馬達</div> 
### MG90S
- MG90S 是一款輕巧高扭力的金屬齒輪伺服馬達，廣泛應用於機器人控制、航模、遙控車船以及各類自動化專案。它的內部齒輪採用金屬材質，大幅提升耐磨性與壽命，相較於塑膠齒伺服馬達更適合需要頻繁動作與承受較大負載的應用。

    MG90S 可透過 PWM 訊號控制角度輸出（通常在 0～180 度之間），且體積小巧，適合安裝於空間受限的裝置中。
 
#### 主要特色：
- 動作角度：0°～180°（取決於控制訊號）
- 工作電壓：4.8V～6.0V
- 扭力輸出：約 1.8 kg·cm（4.8V）、2.2 kg·cm（6.0V）
- 反應速度：約 0.1 秒 / 60°（6.0V 無負載）
- 齒輪材質：全金屬齒輪，耐用穩定
- 重量：約 13.4g
- 接頭：3-pin（PWM 訊號、VCC、GND）
<div align="center">

</div>

## <div align="center">直流減速馬達</div> 
### JGA25-370
- JGA25-370 是一款結合高扭力減速機構與旋轉編碼器的直流馬達，適合用於需要精準速度與位置控制的應用。馬達主體為 370 規格直流馬達，搭配金屬齒輪減速箱，具備高扭力輸出與穩定運轉特性。尾端附帶霍爾效應編碼器，可回傳轉速與轉動方向，支援 PID 控制或路徑追蹤等閉迴路控制系統。

    此款馬達廣泛應用於自走車、機械手臂、履帶車、智慧載具等開發項目，並可與 Arduino、Raspberry Pi、STM32 等開發平台輕鬆整合。

#### 主要特色：
- 馬達型號：370 DC 馬達
- 電壓範圍：6V ～ 12V（依版本）
- 轉速：常見版本有 50rpm、100rpm、200rpm、625rpm、1000rpm（依減速比）
- 扭力：依減速比而異，可達 1kg·cm 以上
- 齒輪：金屬齒輪，耐用抗磨損
- 軸徑：6mm（D 型軸）
- 編碼器：霍爾編碼器，雙通道輸出（A/B 相），一般為 11脈衝/圈（經減速後脈衝數提升）
- 編碼器輸出：TTL 輸出，可用中斷方式讀取
<div align="center">

</div>

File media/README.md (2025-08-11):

# Media

## Vechicle Photos

<table>
    <tr>
        <th>TOP</th>
        <th>FRONT</th>
        <th>LEFT</th>
    </tr>
    <tr>
        <th></th>
        <th></th>
        <th></th>
    </tr>
    <tr>
        <th>BOTTOM</th>
        <th>REAR</th>
        <th>RIGHT</th>
    </tr>
    <tr>
        <th></th>
        <th></th>
        <th></th>
    </tr>
</table>

## Team Photos

### Our Team

<table>
    <tr>
        <th></th>
        <th></th>
    </tr>
</table>

### Member

<table>
    <tr>
        <th>蔡宜成 Tim</th>
        <th>林仲斌 Leo</th>
        <th>賴孟承 Lai</th>
    </tr>
    <tr>
        <th></th>
        <th></th>
        <th></th>
    </tr>
</table>

## Demonstration Videos

* [`Open Challenge Video Link`](https://www.youtube.com/watch?v=9j58IBostGY)

* [`Obstacle Challenge Video Link`](https://www.youtube.com/watch?v=Z6zT3QnwcCs&ab_channel=UchihaItachi%E5%AE%87%E6%99%BA%E6%92%A5%E6%9F%9A)

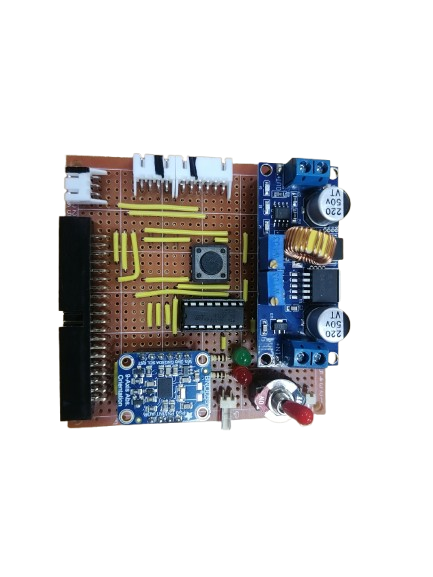
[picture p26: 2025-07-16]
img/circuit_board_front.png

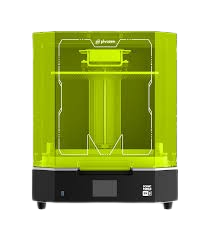
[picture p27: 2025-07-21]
img/Light_curing.png

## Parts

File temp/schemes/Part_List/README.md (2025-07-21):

- [Raspberry Pi 4 Model B - 8GB RAM](https://www.raspberrypi.com/products/raspberry-pi-4-model-b/)
- [JGA25-370 DC 12V 620RPM Gearbox Motor](https://www.amazon.com/JGA25-370-Electric-Torque-1360RPM-620rpm/dp/B0DJXMDH4Y?th=1)
- [MG90S Micro Servo Motor](https://www.taiwaniot.com.tw/product/mg90s-14g%E5%85%A8%E9%87%91%E5%B1%AC%E9%BD%92%E8%88%B5%E6%A9%9F-servo-%E4%BC%BA%E6%9C%8D%E6%A9%9F/)
- [L298N](https://www.jmaker.com.tw/products/product293)
- [BNO055 IMU](https://www.remisys.com.tw/products/bno055-absolute-orientation-sensor)
- [SONY IMX477](https://www.taiwaniot.com.tw/product/sony-imx477-%E6%94%9D%E5%BD%B1%E9%8F%A1%E9%A0%AD%E6%A8%A1%E7%B5%84-1230%E8%90%AC%E5%83%8F%E7%B4%A0-160%E5%BB%A3%E8%A7%92-%E6%94%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)
- [Desire Power V8 11.1V 1300mAh 35C-70C 3S 鋰聚合物電池](https://shopee.tw/-%E6%90%9E%E5%95%A5%E9%A3%9B%E6%A9%9F-Desire-Power-V8-11.1V-1300mAh-35C-70C-3S%E9%8B%B0%E9%9B%BB%E6%B1%A0LiPo-BSMI%E8%AA%8D%E8%AD%89-i.17393576.203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)
- [High Current 5A Constant Voltage Constant Current Buck Power Supply Module](https://shopee.tw/%E8%8E%86%E6%B4%8B-DC1.25%EF%BD%9E36V-5A%E6%81%86%E5%A3%93%E6%81%86%E6%B5%81%E7%A9%A9%E5%A3%93%E9%99%8D%E5%A3%93%E6%A8%A1%E7%B5%84-1483-%E5%A4%A7%E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)
- [12mm Tact Switch 4Pin](https://www.ltc.com.tw/products/swtack126q3?srsltid=AfmBOoqa5NC68h5vsjJj31R0cWCgGWVAmQfi6TSZ_v5ukIABcZczbuqb)
- [TCS34725 RGB color sensor](https://www.taiwansensor.com.tw/product/tcs34725-rgb-%E9%A1%8F%E8%89%B2%E8%BE%A8%E8%AD%98%E6%84%9F%E6%B8%AC%E5%99%A8-color-sensor-%E9%A1%8F%E8%89%B2%E6%84%9F%E6%B8%A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)
- [6x6x5mm微動輕觸開關](https://www.jmaker.com.tw/products/product136)
- [LDROBOT D100 LiDAR Kit](https://www.robotshop.com/products/ldrobot-d100-lidar-kit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)
- [搖頭開關 3A-250VAC 6A-125VAC MTS-1連動開關](https://shopee.tw/product/26482219/490434892)
- [XH2.5mm 4P 公座90度](https://jin-hua.com.tw/page/product/show.aspx?num=10084&lang=TW)
- [XH2.5mm 3P 公座90度](https://jin-hua.com.tw/page/product/show.aspx?num=10087&lang=TW)
- [XH2.5mm 6P母座]()
- [XH2.5mm 4P母座](https://jin-hua.com.tw/page/product/show.aspx?num=10126&lang=TW)
- [XH2.5mm 3P母座](https://jin-hua.com.tw/page/product/show.aspx?num=10128&lang=TW)
- [2.54mm 2P公座90度](https://jin-hua.com.tw/page/product/show.aspx?num=10648&lang=TW)
- [2.54mm 2P母座](https://jin-hua.com.tw/page/product/show.aspx?num=36934&lang=TW)
- [3mm白俄椴木板 30x45cm](https://woodmall.com.tw/shop/product/3mm-s%e7%b4%9a-%e7%99%bd%e4%bf%84%e6%a4%b4%e6%9c%a8%e6%9d%bf-30x45cm/)

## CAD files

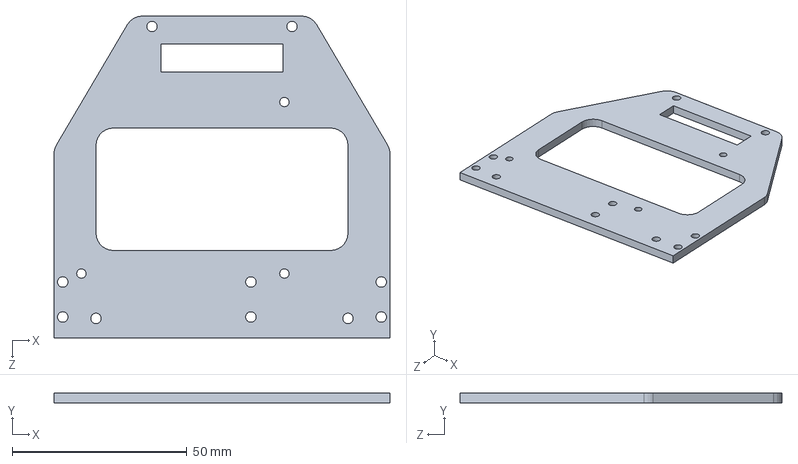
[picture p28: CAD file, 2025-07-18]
hardware/SLDPRT/Plate_2.SLDPRT
96.0 x 3.00 x 92.0 mm

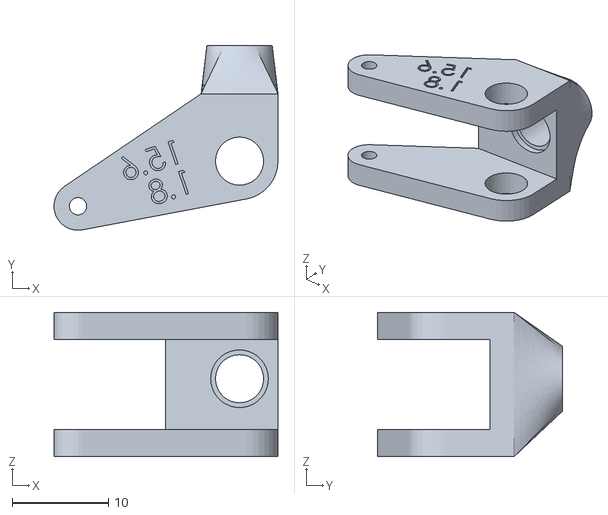
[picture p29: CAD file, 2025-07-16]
temp/schemes/cad_files/ST Knuckle-18-L.STL
23.3 x 19.2 x 15.0

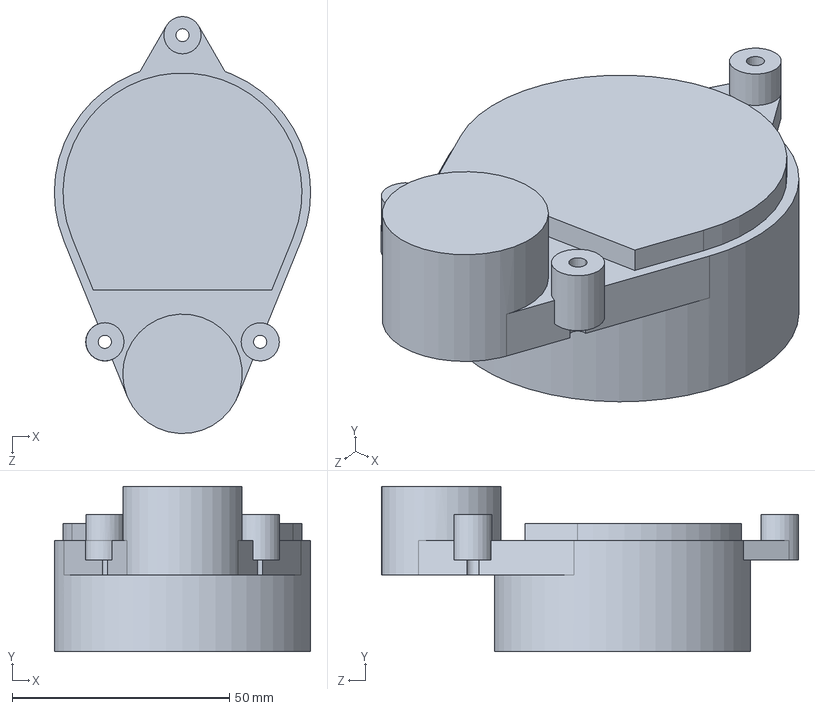
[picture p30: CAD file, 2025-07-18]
hardware/SLDPRT/D100 Lidar.SLDPRT
59.0 x 38.0 x 96.0 mm

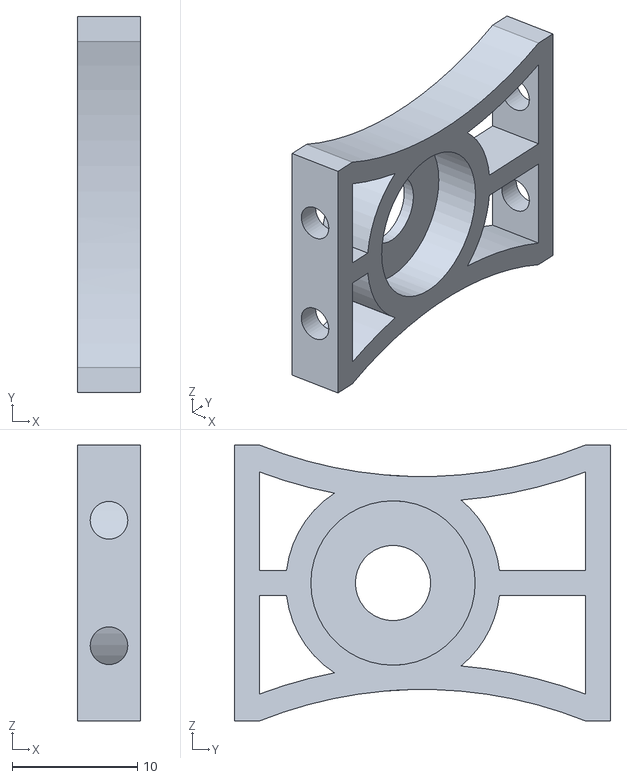
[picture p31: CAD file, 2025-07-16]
temp/schemes/cad_files/Bearing Holder_1.STL
5.00 x 30.0 x 22.0

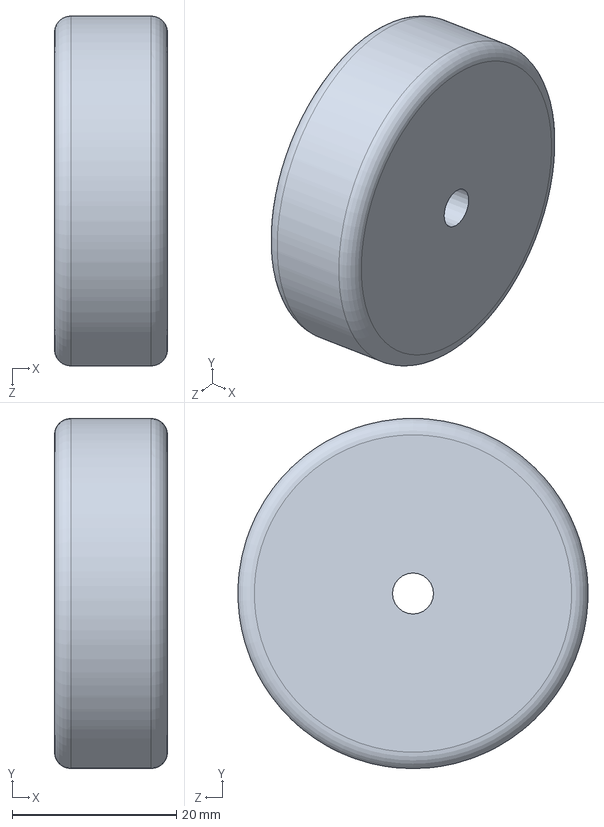
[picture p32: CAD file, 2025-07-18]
hardware/SLDPRT/Front wheel.SLDPRT
13.8 x 42.7 x 42.7 mm

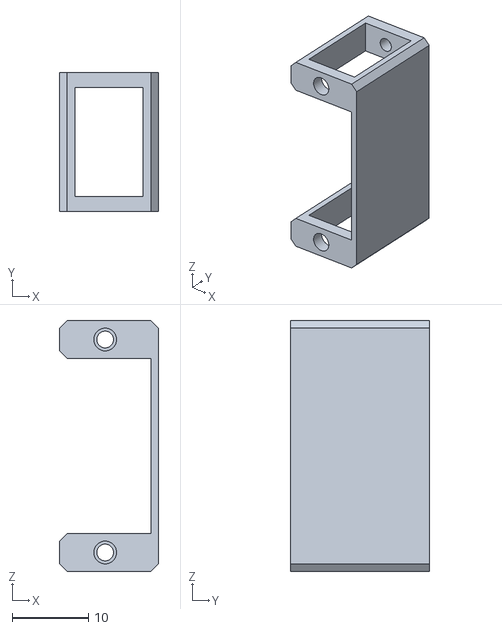
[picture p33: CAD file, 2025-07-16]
temp/schemes/cad_files/Servo Holder.STL
13.0 x 18.3 x 33.0

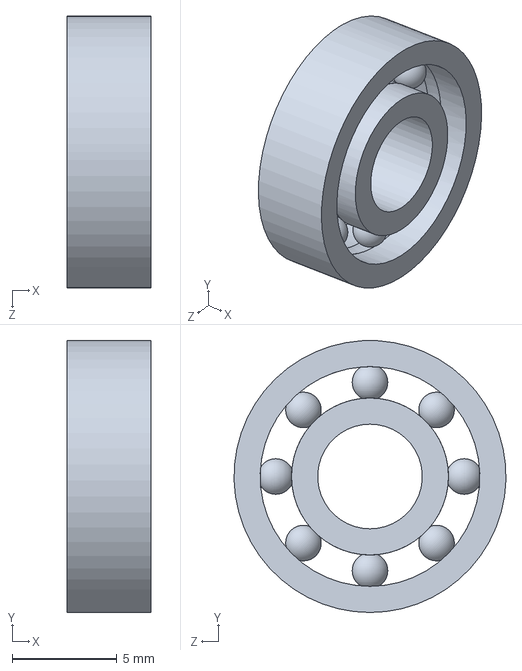
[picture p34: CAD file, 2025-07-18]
hardware/SLDPRT/NSK695z.SLDPRT
4.00 x 13.0 x 13.0 mm

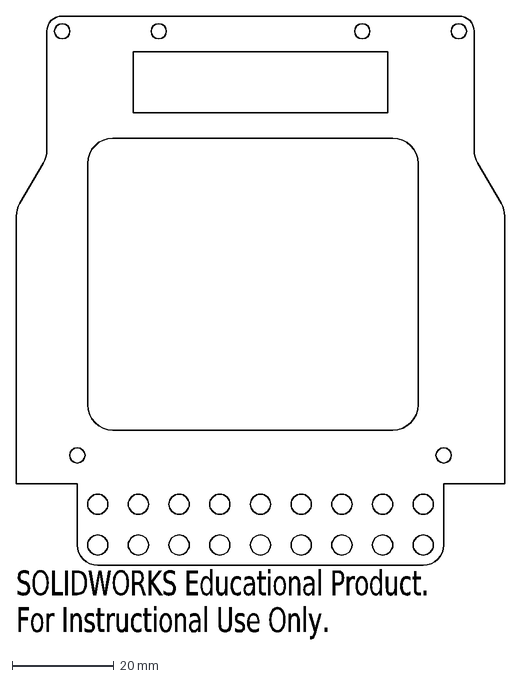
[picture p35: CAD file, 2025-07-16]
temp/schemes/cad_files/Plate_3.DXF
SOLIDWORKS Educational Product.
For Instructional Use Only.

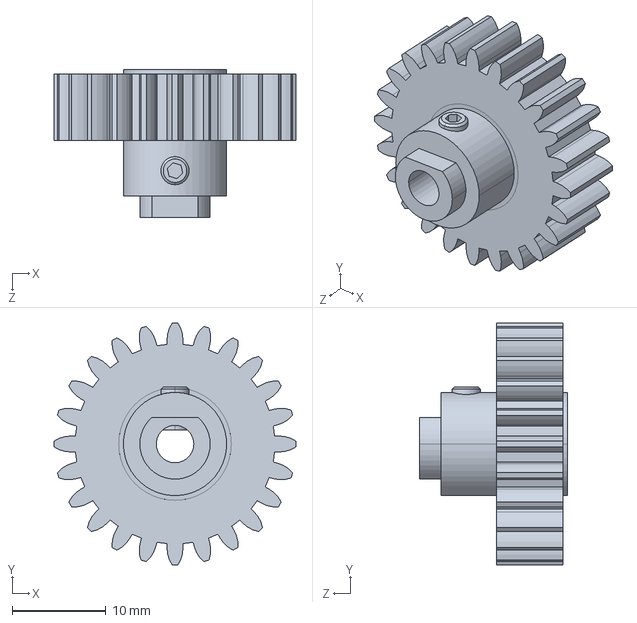
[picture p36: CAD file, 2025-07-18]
hardware/SLDPRT/12-0024.SLDPRT
25.8 x 25.8 x 15.8 mm

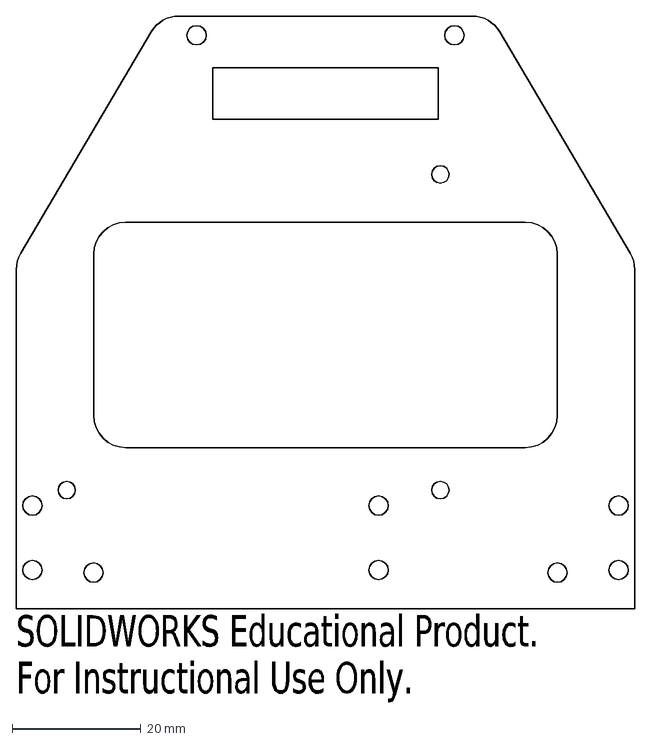
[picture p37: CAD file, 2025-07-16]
temp/schemes/cad_files/Plate_2.DXF
SOLIDWORKS Educational Product.
For Instructional Use Only.

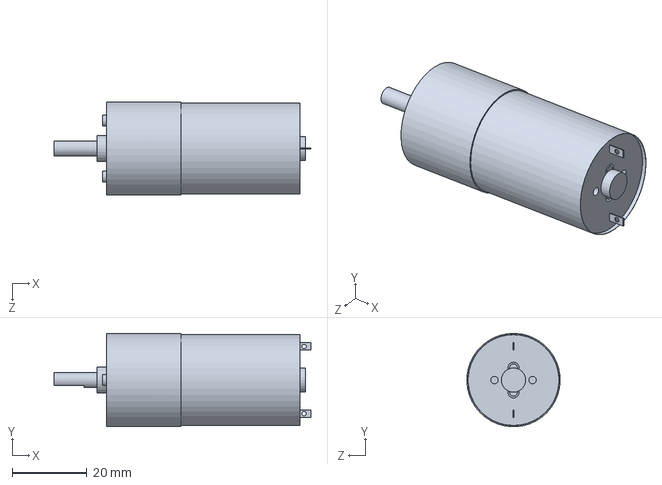
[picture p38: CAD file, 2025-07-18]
hardware/SLDPRT/DC motor.SLDPRT
68.8 x 25.0 x 25.0 mm

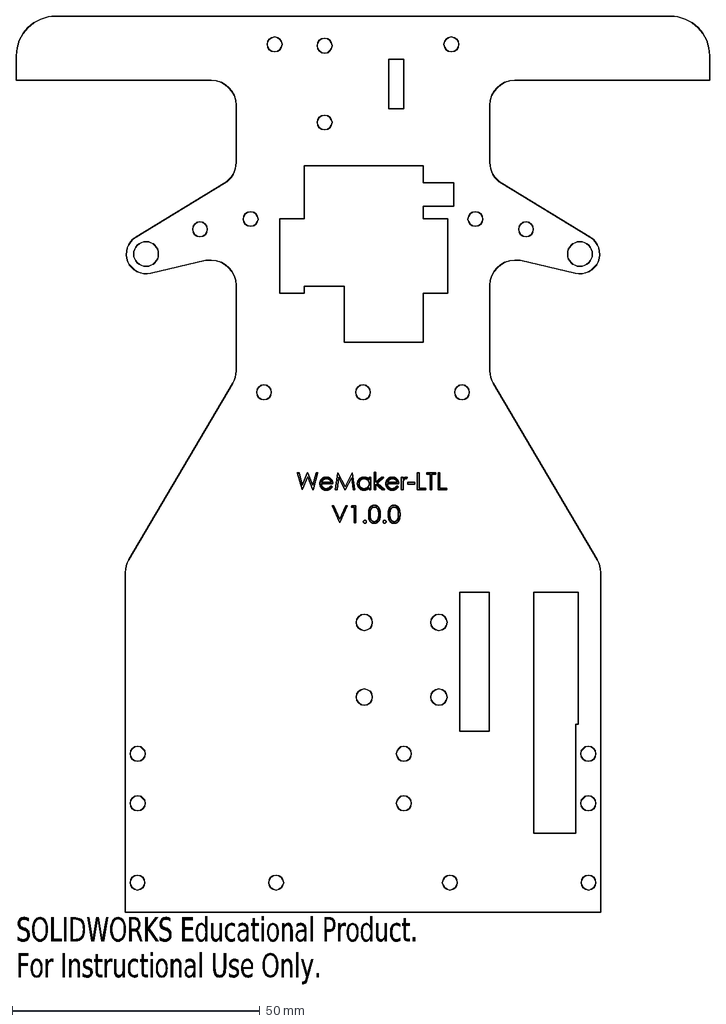
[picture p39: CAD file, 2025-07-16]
temp/schemes/cad_files/Plate.DXF
SOLIDWORKS Educational Product.
For Instructional Use Only.

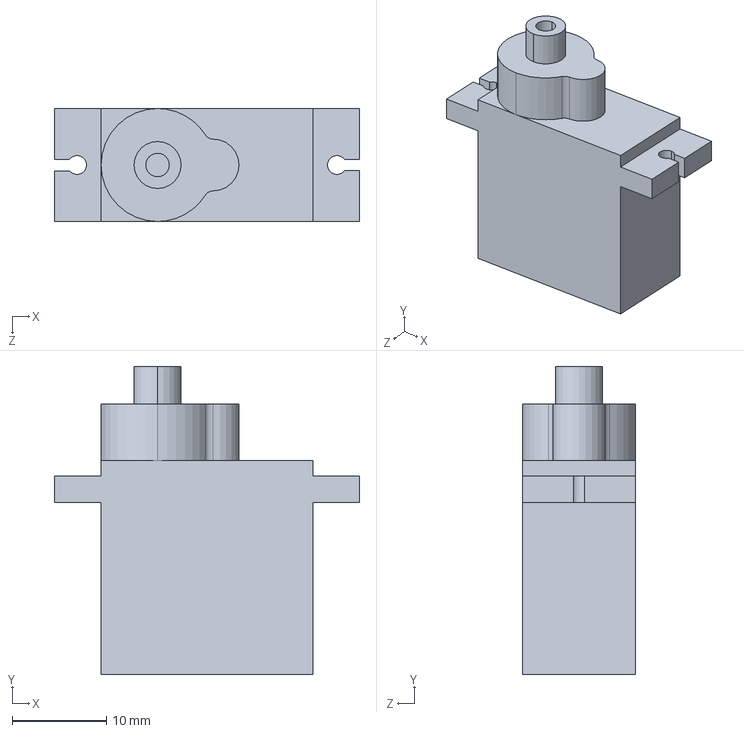
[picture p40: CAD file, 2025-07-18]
hardware/SLDPRT/mg90s.SLDPRT
32.4 x 32.8 x 12.0 mm

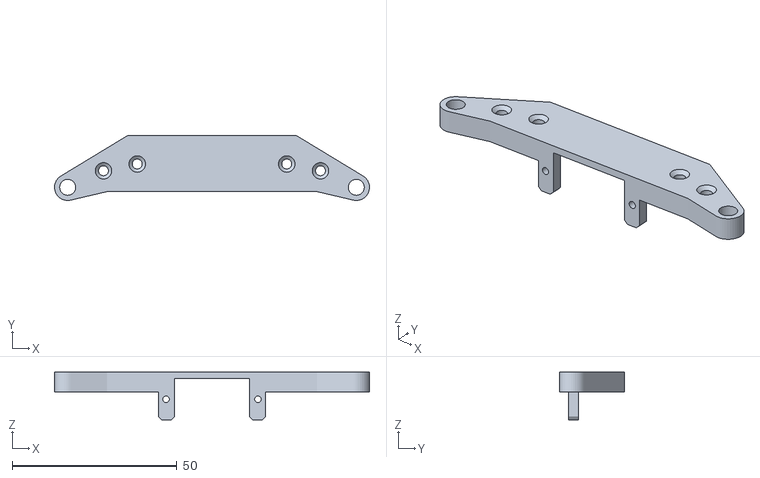
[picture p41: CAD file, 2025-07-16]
temp/schemes/cad_files/Steering Holdor-1-1.STL
95.6 x 19.7 x 14.5

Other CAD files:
hardware/SLDPRT/Raspberry Pi 4 Model B.SLDASM
hardware/SLDPRT/Vehicle2025_v1.0.0.SLDASM
temp/schemes/cad_files/ST Knuckle-18.STL
hardware/SLDPRT/3S Battery.SLDPRT
hardware/DXF/Braking_Arm.DXF
hardware/DXF/Plate_3.DXF
hardware/SLDPRT/Bearing Holder_1.SLDPRT
hardware/SLDPRT/Braking Arm.SLDPRT
hardware/SLDPRT/Game Feiled Wall Holder - Inside.SLDPRT
hardware/SLDPRT/Game Feiled Wall Holder - Outside.SLDPRT
hardware/SLDPRT/GearHolder.SLDPRT
hardware/SLDPRT/L- Motor holder.SLDPRT
hardware/SLDPRT/LEGO Differential.SLDPRT
hardware/SLDPRT/Plate.SLDPRT
hardware/SLDPRT/Plate_3.SLDPRT
hardware/SLDPRT/Rear wheels.SLDPRT
hardware/SLDPRT/ST Knuckle-18-L.SLDPRT
hardware/SLDPRT/ST Knuckle-18.SLDPRT
hardware/SLDPRT/Servo Arm.SLDPRT
hardware/SLDPRT/Servo Holder.SLDPRT
hardware/SLDPRT/Steering Holdor-1-1.SLDPRT
hardware/SLDPRT/lego axle #5.SLDPRT
hardware/SLDPRT/lego axle connector.SLDPRT
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

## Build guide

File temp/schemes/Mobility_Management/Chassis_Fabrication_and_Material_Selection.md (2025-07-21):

## <div align="center">底盤製作與材料選擇</div> 

- ### 底盤材料選擇
我們的機構底盤採用了 3mm 椴木板搭配雷射切割機製作。椴木板屬於質地細緻、密度較低的闊葉木材料，由多層椴木單板壓合而成，結構穩定且重量輕盈，非常適合使用雷射切割機進行高精度加工，能有效提升底盤的製作效率與精度。
- 優點
    - 質地輕盈易於加工
    - 表面平整適合雷射雕刻精細作業

<div style="text-align: center;">
  <table>
    <tr>
      <th style="text-align: center;">雷切機機台</th>
      <th style="text-align: center;">3mm 椴木板</th>
    </tr>
    <tr>
      <td>
        雷切機機台
      </td>
      <td>
        3mm 椴木板
      </td>
    </tr>
  </table>
</div>

- ### 轉向機構材料選擇
我們採用光固化技術製作轉向機構。光固化是一種透過特定波長的光（通常為紫外光 UV）觸發光敏樹脂聚合反應，將液態樹脂快速轉化為固體的加工技術，具備高精度與快速成型的優勢，非常適合用於製作細節複雜且結構精細的機械零件。

- 優點
    - 高精度成型可達到 0.05mm 甚至更細的細節，適合製作複雜結構與精密零件
    - 成品表面細緻，後處理相對簡單，適合直接使用
    - 可一體列印成型，減少零件數量與組裝誤差

<div style="text-align: center;">
  <table>
    <tr>
      <th style="text-align: center;">光固化機台</th>
      <th style="text-align: center;">光固化成品</th>
    </tr>
    <tr>
      <td>
        光固化機台
      </td>
      <td>
        光固化成品
      </td>
    </tr>
  </table>
</div>

- ### 電路板
自行購買材料設計焊接而成。
<div style="text-align: center;">
  <table>
    <tr>
      <th style="text-align: center;">電路板上視圖</th>
      <th style="text-align: center;">電路板下視圖</th>
    </tr>
    <tr>
      <td>
        電路板上視圖
      </td>
      <td>
        電路板下視圖
      </td>
    </tr>
  </table>
</div>

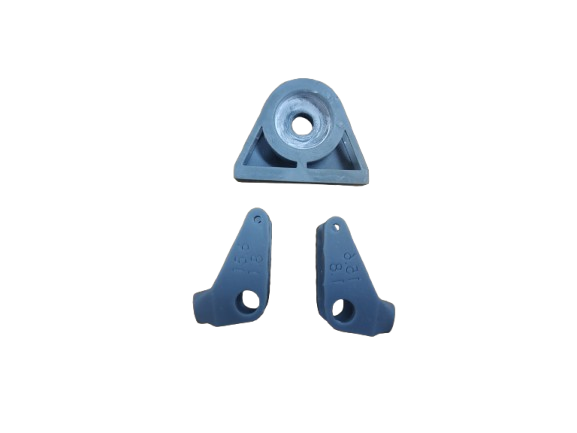
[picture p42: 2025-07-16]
img/3D_Printer.png

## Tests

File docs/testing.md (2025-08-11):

# Testing
## 測試流程
#### 1. 硬體檢查與模組連接測試

- 逐一檢查馬達驅動板、伺服馬達、感測器（LiDAR、IMU、攝影機）連接狀況。

- 使用簡單測試程式確認每個模組能正確回傳數據或動作。

#### 2. 感測器數據校正

- 使用固定距離與已知角度的環境，測試 LiDAR 與 IMU 的量測精度，並記錄偏差值。

- 校正攝影機白平衡與 HSV 顏色範圍，確保在不同光照下辨識一致性。

#### 3. 基礎行駛測試

- 在開放空間內測試直線行駛與原地旋轉，檢查速度控制與角度精準度。

- 驗證 PWM 速度曲線與實際車速的對應關係。

#### 4. 功能整合測試

- 將感測器輸入與馬達控制結合，測試車輛在偵測到牆或積木時的反應時間與避障路徑。

#### 5. 完整場地模擬測試

- 在模擬比賽場地進行多次繞圈與避障測試，檢查系統在長時間運行下的穩定性與精度。

## 遇到的困難與解決方式
| 困難 | 描述 | 解決方式 |
| --- | --- | --- |
| **光達量測偏移** | 車輛轉向時，光達的距離數據因角度造成投影誤差 | 引入 IMU 角度補償公式（cos 修正 + 微調係數）還原垂直距離  |
| **顏色辨識受光照影響**  | HSV 範圍在不同燈光下會導致辨識錯誤 | 在程式中增加多組顏色範圍，根據光照亮度動態切換 |
| **伺服馬達轉角不一致**  | 長時間使用後，伺服轉角有累積偏差 | 啟動時加入中立位置校正，並限制最大轉角避免卡死 |
| **電壓不穩導致系統重啟** | 18650 電池供電不足時樹莓派重啟 | 改用 LiPo 3S 11.1V 電池 + 降壓模組，提供更穩定的電壓 |
| **影像處理延遲** | 即時影像處理造成運算瓶頸 | 降低解析度與處理頻率，或在特定情況才啟用影像辨識 |

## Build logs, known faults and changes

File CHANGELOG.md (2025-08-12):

# Change Log

* 2025/08/11 Release National version for national championship.

* 2025/07/25 Release first version for online rewiew.

* 2025/06/24 Initial - commit.

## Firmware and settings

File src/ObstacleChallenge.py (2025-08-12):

# === 導入所需函式庫 ===
# 匯入影像處理(cv2, numpy)、多執行緒(threading)、自訂功能(function)、佇列(Queue)、資料序列化(pickle)、樹莓派相機(Picamera2)等模組
import cv2
import numpy as np
import threading
from function import *
from queue import Queue
import pickle
from picamera2 import Picamera2

# 建立 pigpio 介面物件，用於控制 Raspberry Pi 的 GPIO
pi = pigpio.pi()

# PWM 驅動馬達時會在電源線上產生高頻脈衝，造成電壓波動與 EMI（電磁干擾）。
# 這段程式在感測器初始化前先將 PWM 腳位強制設為低電平，等感測器啟動完成後再恢復馬達控制。
pi.set_mode(11, pigpio.LOW)
pi.set_mode(21, pigpio.LOW)

# 初始化 Picamera2，設定低解析度(480x360)提升處理速度
# 固定曝光與亮度，提升顏色飽和與銳利度，確保影像辨識穩定
frame_queue = Queue(maxsize=2)
imcap = Picamera2()
config = imcap.create_preview_configuration(main={"size": (480, 360)})
imcap.configure(config)
imcap.start() 
imcap.set_controls({
    "AeExposureMode": 0,               # 關自動曝光
    "ExposureValue": 0.5,              # 稍微降低曝光
    "Brightness": 0.3,                 # 降低整體亮度
    "Saturation": 1,                   # 增加物體顏色強度
    "Sharpness": 0.6,                  # 輕微提升銳利度
    "AwbEnable": True,                 # 關自動白平衡
})

# === 從自訂 function 模組匯入並初始化感測器物件 ===
reader = D100Reader()  # 超音波測距模組
tcs34725 = TCS34725()  # 顏色感測器
bno = BNO055()         # 陀螺儀(IMU) 

# === 計數與狀態控制 ===
line_count = 0                # 記錄當前通過的線數(0~3)，用來對應 dir_array 切換車頭目標方向
total_line_count = 0          # 總共完成的線數
dir_array = [0, 90, 180, 270] # 車頭朝向的方向角度
avoidance_active = True       # 當前是否處於積木閃避階段，結束後停止該迴圈
program_active = True         # 控制整體程式運行，直到全部跑完才結束

# === 距離校正參數 ===
distance_corrected = False    # 是否已完成距離校正

# 是否啟用經陀螺儀校正後的光達數據（True 表示使用校正後數據）
enable_calibrated_lidar  = False

# PD 控制器中上一個誤差值，用於計算微分項（derivative）
last_error = 0

# === 偵測到的物體邊界框 (x, y, w, h) ===
rect_left_wall = (0, 0, 0, 0)     # 鏡頭偵測到的左牆資訊用來跟綠色斜線判斷
rect_right_wall = (0, 0, 0, 0)    # 鏡頭偵測到的右牆資訊用來跟紅色斜線判斷

# === 牆面資訊 ===
left_wall_y = left_wall_h = 0
right_wall_y = right_wall_h = 0

# === 車輛位置 (影像座標系) ===
car_x = 240
car_y = 260

def read_file():
     """
    從儲存的 pickle 檔案中讀取各顏色的 HSV 範圍設定，
    並轉換成 numpy 陣列以供影像處理使用。
    支援顏色：Green, Red, Pink, Orange, Blue, Black。
    """
    global green_lower, green_upper, red_lower, red_upper, black_lower, black_upper, pink_lower, pink_upper, orange_lower, orange_upper, blue_lower, blue_upper, bl_lower, bl_upper
    with open('save_file/HSV_Green.p', mode='rb') as f:
        file = pickle.load(f)
    lower_green = file['Lower']
    upper_green = file['Upper']
    print('Green_Lower:' + str(lower_green))
    print('Green_Upper:' + str(upper_green))
    
    with open('save_file/HSV_Red.p', mode='rb') as f:
        file = pickle.load(f)
    lower_red = file['Lower']
    upper_red = file['Upper']
    print('Red_Lower:' + str(lower_red))
    print('Red_Upper:' + str(upper_red))
    
    with open('save_file/HSV_Pink.p', mode='rb') as f:
        file = pickle.load(f)
    lower_pink = file['Lower']
    upper_pink = file['Upper']
    print('Pink_Lower:' + str(lower_pink))
    print('Pink_Upper:' + str(upper_pink))
    
    with open('save_file/HSV_Orange.p', mode='rb') as f:
        file = pickle.load(f)
    lower_orange = file['Lower']
    upper_orange = file['Upper']
    print('Orange_Lower:' + str(lower_orange))
    print('Orange_Upper:' + str(upper_orange))
    
    with open('save_file/HSV_Blue.p', mode='rb') as f:
        file = pickle.load(f)
    lower_blue = file['Lower']
    upper_blue = file['Upper']
    print('Blue_Lower:' + str(lower_blue))
    print('Blue_Upper:' + str(upper_blue))
    
    with open('save_file/HSV_Black.p', mode='rb') as f:
        file = pickle.load(f)
    lower_black = file['Lower']
    upper_black = file['Upper']
    print('Black_Lower:' + str(lower_black))
    print('Black_Upper:' + str(upper_black))
    
    red_lower = np.array(lower_red, np.uint8) 
    red_upper = np.array(upper_red, np.uint8)
    green_lower = np.array(lower_green, np.uint8)
    green_upper = np.array(upper_green, np.uint8)
    pink_lower = np.array(lower_pink, np.uint8)
    pink_upper = np.array(upper_pink, np.uint8)
    orange_lower = np.array(lower_orange, np.uint8)
    orange_upper = np.array(upper_orange, np.uint8)
    blue_lower = np.array(lower_blue, np.uint8)
    blue_upper = np.array(upper_blue, np.uint8)
    black_lower = np.array(lower_black, np.uint8)
    black_upper = np.array(upper_black, np.uint8)

def gyro_read():
    """
    以固定時間間隔讀取 BNO055 陀螺儀的相對角度，
    並依照 line_count 對應的方向做修正。
    持續讀取直到 program_active 為 False。
    """
    global gyro, line_count, program_active
    while program_active:
        gyro = bno.relative(dir_array[line_count])
        time.sleep(0.01)
        
def color_read():
    """
    以固定時間間隔讀取 TCS34725 光感值，
    持續讀取直到 program_active 為 False。
    """
    global lum, program_active
    tcs34725 = TCS34725()
    while program_active:
        lum = tcs34725.readluminance()['c']
        time.sleep(0.01)
        
def line_detect():
    """
    偵測並計數地場地地面線條：
    在轉彎處會有兩條線，需等兩條皆通過後再延遲 2.5 秒啟動後續偵測。
    """
    global line_count, total_line_count, avoidance_active , lum
    while avoidance_active :
        while lum > 30 and avoidance_active :
            time.sleep(0.001)
        if line_count + 1 == 4:
            line_count = 0
        else:
            line_count += 1
        total_line_count+=1
        while lum <= 30 and avoidance_active :
            time.sleep(0.001)  
        while lum > 30 and avoidance_active :
            time.sleep(0.001)
        time.sleep(2.5)
           
def read():
    """
    持續從光達讀取距離資料，根據是否啟用陀螺儀校正決定如何處理：
    - 若啟用，則根據校正後角度修正計算前、左、右方最短距離（單位公分）
    - 未啟用則直接使用光達讀取的原始距離
    """
    global gyro, front, left, right, program_active, front_1, left_1, right_1, enable_calibrated_lidar, right_special
    while program_active:
        ranges, angle_min, angle_increment, front_1, left_1, right_1, right_special = reader.get_latest_distances()
        if enable_calibrated_lidar  == True:
            front_min = 9999
            left_min = 9999
            right_min = 9999
            for i, dist in enumerate(ranges):
                if math.isnan(dist) or dist == 0:
                    continue
                angle = angle_min + i * angle_increment
                deg = math.degrees(angle)
                deg = (deg + 180) % 360 - 180
                corrected_angle = deg + gyro
                if -15 <= corrected_angle <= 15:
                    front_min = min(front_min, dist)
                elif -100 <= corrected_angle <= -80:
                    left_min = min(left_min, dist)
                elif 80 <= corrected_angle <= 100:
                    right_min = min(right_min, dist)

            # 距離轉為公分
            front = int(front_min*100) if front_min < 9999 else -1
            right = int(left_min*100) if left_min < 9999 else -1
            left = int(right_min*100) if right_min < 9999 else -1

# 函式(calculate_servo_angle_red、calculate_servo_angle_green)分別計算紅色與綠色積木的伺服角度，用以閃避相對牆壁
# 兩者邏輯相似，差異在於使用不同牆壁區域與變數
# 根據積木與車頭位置、牆壁判斷轉向角度，並結合陀螺儀校正進行動態調整
def calculate_servo_angle_red(cx, cy, bx, by):
    # 判斷從車頭點 (315, cy) 到積木點 (bx+75, by) 的線是否與右牆矩形相交
    intersects, clipped_pt1, clipped_pt2 = cv2.clipLine(rect_right_wall, (315, cy), (bx+75, by))

    dx_raw = bx - cx    # x方向原始差值，帶符號用於方向判斷
    dx = abs(dx_raw)    # x方向距離（絕對值）
    dy = abs(by - cy)   # y方向距離（絕對值）

    # 若dx為0，代表垂直線，無斜率，使用陀螺儀角度調整伺服角度，並限制範圍
    if dx == 0:
        servo_angle = gyro * 1.2
        servo_angle = constrain(servo_angle, -50, 50)
        servo.angle(servo_angle)
    # 積木在右側，且線未碰牆或牆位置較遠，依斜率映射角度，向右轉
    elif bx > cx and (not intersects or right_wall_y+right_wall_h < 240):
        m = dy/dx
        m = constrain(m, 0, 3)
        servo_angle = mapping(m, 0, 3, 50, 10) 
        servo.angle(servo_angle)
    # 線與牆相交且陀螺儀角度大於5度，調整斜率以避開牆壁
    elif intersects and abs(gyro) > 5:
        # 取得線與牆交點最大x值，計算與牆的x方向差距
        x_man_overlap = max(clipped_pt1[0], clipped_pt2[0])
        rect_right_x = rect_right_wall[0]
        diff = x_man_overlap - rect_right_x
        # 根據dx_raw方向調整斜率的x分量，避免撞牆
        if dx_raw > 0:
            dx_adjusted = dx_raw - diff - 22  # 第一象限處理
        else:
            dx_adjusted = dx_raw + diff - 22  # 第二象限處理
        # 避免dx_adjusted為0造成除錯誤
        if abs(dx_adjusted) < 1e-5:
            dx_adjusted = 1e-5 if dx_adjusted >= 0 else -1e-5
        m = dy / dx_adjusted
        m_abs = abs(m)
        m_abs = constrain(m_abs, 0, 3)
        # 根據修正後的dx_adjusted決定轉向方向和角度
        if dx_adjusted > 0:
            servo_angle = mapping(m_abs, 0, 3, 50, 0)
            servo.angle(servo_angle)  # 右轉
        else:
            servo_angle = mapping(m_abs, 0, 3, 30, 15)
            servo.angle(-servo_angle) # 左轉
    # 若積木與車頭距離過近，角度歸零，不轉向
    elif abs(bx - cx) < 75 or abs(by - cy) < 60:
        servo.angle(0)    
    # 其他情況，依陀螺儀角度或斜率進行轉向調整
    elif abs(gyro) > 50:
        m = dy/dx
        m = constrain(m, 0, 3)
        servo_angle = mapping(m, 0, 3, 30, 10)
        servo.angle(-servo_angle)
    else:
        servo_angle = gyro * 1.2
        servo_angle = constrain(servo_angle, -50, 50)
        servo.angle(servo_angle)

def calculate_servo_angle_green(cx, cy, bx, by):
    intersects, clipped_pt1, clipped_pt2 = cv2.clipLine(rect_left_wall, (175, cy), (bx-65, by))
    dx = abs(bx - cx)
    dy = abs(by - cy)
    if dx == 0:
        servo_angle = gyro * 1.2
        servo_angle = constrain(servo_angle, -50, 50)
        servo.angle(servo_angle)
    elif bx < cx and (not intersects or left_wall_y+left_wall_h < 240):
        m = dy/dx
        m = constrain(m, 0, 3)
        servo_angle = mapping(m, 0, 3, 50, 10)
        servo.angle(-servo_angle)
        print("dodge:", -servo_angle)
    elif intersects and abs(gyro) > 5:
        x_min_overlap = min(clipped_pt1[0], clipped_pt2[0])
        rect_right_x = rect[0] + rect[2]
        diff = rect_right_x - x_min_overlap
        if dx > 0:
            dx_adjusted = dx - (diff - 15)  # 第一象限處理
        else:
            dx_adjusted = dx + (diff - 15)  # 第二象限處理
        if abs(dx_adjusted) < 1e-5:
            dx_adjusted = 1e-5 if dx_adjusted >= 0 else -1e-5
        m = dy / dx_adjusted
        m_abs = abs(m)
        m_abs = constrain(m_abs, 0, 3)
        if dx > 0:
            servo_angle = mapping(m_abs, 0, 3, 20, 10)
            servo.angle(servo_angle)  # 右轉
        else:
            servo_angle = mapping(m_abs, 0, 3, 50, 10)
            servo.angle(-servo_angle) # 左轉
        print("out:", servo_angle)
        
    elif abs(bx - cx) < 75 or abs(by - cy) < 60:
        servo.angle(0)
    else:
        if abs(gyro) > 50:
            m = dy/dx
            m = constrain(m, 0, 3)
            servo_angle = mapping(m, 0, 3, 30, 10)
        else:
            servo_angle = gyro * 1.1
            servo_angle = constrain(servo_angle, -40, 40)
        servo.angle(servo_angle)

def distance_correction(right_1, servo, target_distance=34):
    """
    利用 PD 控制器調整伺服角度，使車身與右牆保持固定距離（預設34公分）。
    - right_1*100：實際右側距離（公分）
    - error：實際距離與目標距離的誤差
    - kp, kd：比例與微分控制係數
    - servo_angle：計算後伺服角度，限制在[-25, 25]度範圍內
    回傳值為誤差是否小於等於2公分，代表是否達到校正目標。
    """
    global last_error
    distance = right_1*100
    error = distance - target_distance
    kp = 2.0
    kd = 0.5
    derivative = error - last_error
    last_error = error
    servo_angle = kp * error + kd * derivative
    servo_angle = constrain(servo_angle, -25, 25)
    servo.angle(servo_angle)
    return abs(error) <= 2

read_file()  # 讀取HSV色彩範圍設定檔，初始化顏色辨識參數

if bno.begin() is not True:  # 初始化BNO055陀螺儀，若失敗則顯示錯誤並結束程式
    print("Error initializing device")
    exit()

time.sleep(1)  # 稍作延遲等待硬體穩定
bno.setExternalCrystalUse(True)  # 啟用外部晶振，提高陀螺儀精度
time.sleep(1)

# 啟動多執行緒以非同步方式持續讀取
threading.Thread(target=gyro_read).start()    # 陀螺儀讀取執行緒
threading.Thread(target=color_read).start()   # 光感讀取執行緒
threading.Thread(target=line_detect).start()  # 線條偵測執行緒

# === 從自訂 function 模組匯入並初始化馬達控制物件 ===
servo = servo_motor()  # 伺服馬達物件
Motor = dc_motor()     # 直流馬達物件

# === 車輛從停車格起步 === 
Motor.DC(50)
while gyro > -80:
    servo.angle(75)
Motor.DC(0)
time.sleep(0.5)
while gyro < -10:
    servo.angle(-65)
    Motor.DC(60)
Motor.DC(0)
time.sleep(0.5)

# === 開始執行閃避積木並繞圈 === 
while total_line_count < 13:
    frame = imcap.capture_array()
    frame = cv2.cvtColor(frame, cv2.COLOR_RGB2BGR)
    imageFrame = frame
    imageFrame[250:360, 0:480] = [0, 0, 0]
    imageFrame[0:95, 0:480] = [0, 0, 0]
    hsvFrame = cv2.cvtColor(imageFrame, cv2.COLOR_RGB2BGR)

    red_mask = cv2.inRange(hsvFrame, red_lower, red_upper)
    red_contours, _ = cv2.findContours(red_mask, cv2.RETR_TREE, cv2.CHAIN_APPROX_SIMPLE) 
    
    green_mask = cv2.inRange(hsvFrame, green_lower, green_upper)
    green_contours, _ = cv2.findContours(green_mask, cv2.RETR_TREE, cv2.CHAIN_APPROX_SIMPLE) 
    
    black_mask = cv2.inRange(hsvFrame, black_lower, black_upper)
    kernel = np.ones((5, 5), np.uint8)
    black_mask = cv2.morphologyEx(black_mask, cv2.MORPH_CLOSE, kernel)
    black_mask = cv2.dilate(black_mask, kernel, iterations=2)
    black_contours, _ = cv2.findContours(black_mask, cv2.RETR_TREE, cv2.CHAIN_APPROX_SIMPLE) 
    
    max_y_bottom_red = -1
    closest_tx_red, closest_ty_red, closest_tx_green, closest_ty_green = -1, -1, -1, -1
    significant_red_contours=[]
    significant_green_contours=[]
    left_contours = []
    right_contours = []
    
    max_x_red, max_x_green = 240, 240
    for cnt in black_contours:
        area = cv2.contourArea(cnt)
        if area > 200:
            x, y, w, h = cv2.boundingRect(cnt)
            if x + w/2 < 240: 
                left_contours.append((area, x, y, w, h))
            else:
                right_contours.append((area, x, y, w, h))
    if left_contours:
        largest = max(left_contours, key=lambda x: x[0])
        _, x, y, w, h = largest
        if x < max_x_green:
            max_x_green = x + w + abs(gyro)*0.1
            w = int(w + abs(gyro)*0.2)
            rect_left_wall = (x, y, w, h)
            left_wall_y = y
            left_wall_h = h
        cv2.rectangle(imageFrame, (x, y), (x + w, y + h), (255, 255, 0), 2)
    if right_contours:
        largest = max(right_contours, key=lambda x: x[0])
        _, x, y, w, h = largest
        if x > max_x_red:
            max_x_red = int(x - abs(gyro)*0.25)
            rect_right_wall = (max_x_red, y, w, h)
            right_wall_y = y
            right_wall_h = h
        cv2.rectangle(imageFrame, (max_x_red, y), (max_x_red + w, y + h), (255, 255, 0), 2)
    
    for cnt in red_contours:
        area = cv2.contourArea(cnt)
        if area > 50:
            x, y, w, h = cv2.boundingRect(cnt)
            tx = x + w + 100
            ty = y
            cv2.rectangle(imageFrame, (x, y), (x + w, y + h), (0, 0, 255), 2)
            y_bottom = y + h 
            if y_bottom > max_y_bottom_red+30:
                max_y_bottom_red = y_bottom
                closest_tx_red = x + w + 100 + int(abs(gyro)*0.15)
                closest_ty_red = y
            if closest_tx_red > 100 :
                significant_red_contours.append(cnt)
            cv2.line(imageFrame, (closest_tx_red, closest_ty_red), (car_x, car_y), (0, 0, 255), 2)
            cv2.line(imageFrame, (closest_tx_red+75, closest_ty_red), (315, car_y), (0, 0, 255), 2)
    
    max_y_bottom_green=-1
    for cnt in green_contours:
        area = cv2.contourArea(cnt)
        if area > 100:
            x, y, w, h = cv2.boundingRect(cnt)
            tx = x - 105
            ty = y
            cv2.rectangle(imageFrame, (x, y), (x + w, y + h), (0, 255, 0), 2)
            y_bottom = y + h  
            if y_bottom > max_y_bottom_green+30:
                max_y_bottom_green = y_bottom
                closest_tx_green = x - 105 - int(abs(gyro)*0.15)
                closest_ty_green = y

            if closest_tx_green < 380 :
                significant_green_contours.append(cnt)
            cv2.line(imageFrame, (closest_tx_green, closest_ty_green), (car_x, car_y), (0, 255, 0), 2)
            cv2.line(imageFrame, (closest_tx_green-65, closest_ty_green), (175, car_y), (80, 255, 0), 2)
    
    if significant_red_contours and max_y_bottom_red > max_y_bottom_green+40 and not (significant_green_contours and max_y_bottom_red+40 < max_y_bottom_green):
        calculate_servo_angle_red(car_x, car_y, closest_tx_red, closest_ty_red)
    elif significant_green_contours:
        calculate_servo_angle_green(car_x, car_y, closest_tx_green, closest_ty_green)
    else:
        servo_angle = gyro * 1.4
        servo_angle = constrain(servo_angle, -50, 50)
        servo.angle(servo_angle)
    cv2.imshow("Red Block Detection with Grid", imageFrame)
    if cv2.waitKey(1) & 0xFF == ord('q'):
        break
    Motor.DC(60)

# === 開始執行停車 ===
threading.Thread(target=read).start()
avoidance_active = False
Motor.DC(70)
while lum > 17:
    servo_angle = (gyro+45) * 1.4
    servo_angle = constrain(servo_angle, -45, 45)
    servo.angle(servo_angle)
Motor.DC(45)
while gyro < -100 or gyro > -90:
    servo_angle = gyro * 1.2
    servo_angle = constrain(servo_angle, -50, 50)
    if servo_angle > 0:
        servo_angle*=-1
    servo.angle(servo_angle)
Motor.DC(0)
time.sleep(0.5)
if front_1 > 0.42:
    Motor.DC(30)
    while front_1 > 0.42:
        servo_angle = (gyro+90) * 1.4
        servo_angle = constrain(servo_angle, -50, 50)
        servo.angle(servo_angle)
    Motor.DC(0)
    time.sleep(0.5)
Motor.DC(50)
while abs(gyro) > 5:
    servo_angle = gyro * 1.4
    servo_angle = constrain(servo_angle, -50, 50)
    servo.angle(servo_angle)
enable_calibrated_lidar = True
Motor.DC(33)
while True:
    if (35 - right) > 2 and right != -1 and right_1 > 0.2:
        distance_corrected = distance_correction(right, servo)
    else:
        servo_angle = (gyro+4) * 1.3
        servo_angle = constrain(servo_angle, -50, 50)
        servo.angle(servo_angle)
    if right_special < 0.2:
        break
enable_calibrated_lidar = False
Motor.DC(35)
while right_special < 0.2:
    servo_angle = gyro * 1.4
    servo_angle = constrain(servo_angle, -50, 50)
    servo.angle(servo_angle)
Motor.DC(0)
time.sleep(0.5)
x1, y1 = 360, 0
x2, y2 = 315, 360
m = (y2 - y1) / (x2 - x1)
b = y1 - m * x1
Motor.DC(30)
while right_special >= 0.2:
    frame = imcap.capture_array()
    frame = cv2.cvtColor(frame, cv2.COLOR_RGB2BGR)
    imageFrame = frame
    imageFrame[0:80, 0:480] = [0, 0, 0]
    hsvFrame = cv2.cvtColor(imageFrame, cv2.COLOR_RGB2BGR)
    
    pink_mask = cv2.inRange(hsvFrame, pink_lower, pink_upper)
    pink_contours, _ = cv2.findContours(pink_mask, cv2.RETR_TREE, cv2.CHAIN_APPROX_SIMPLE) 

    for cnt in pink_contours:
        largest_cnt = max(pink_contours, key=cv2.contourArea)
        area = cv2.contourArea(cnt)
        if area > 100:
            x, y, w, h = cv2.boundingRect(cnt)
            cv2.rectangle(imageFrame, (x, y), (x + w, y + h), (255, 0, 255), 2)
            x_on_line = (y - b) / m
            dist_x = x - x_on_line
            cv2.line(imageFrame, (x1, y1), (x2, y2), (0, 0, 255), 2)
            
            if y > 150:
                servo_angle = (gyro-2) * 1.4
                servo_angle = constrain(servo_angle, -5, 5)
                servo.angle(servo_angle)
            else:
                servo_angle = constrain(dist_x*0.2, -5, 5)
                servo.angle(servo_angle)
    
    cv2.imshow("Red Block Detection with Grid", imageFrame)
    if cv2.waitKey(1) & 0xFF == ord('q'):
        break

Motor.DC(0)
bno.setExternalCrystalUse(True)
time.sleep(1)
servo.angle(-70)
while gyro < 55:
    Motor.DC(45)
Motor.DC(-10)
time.sleep(0.3)
Motor.DC(0)
set_gyro = gyro
time.sleep(0.5)
Motor.DC(-29)
while right_special > 0.2:
    servo_angle = (gyro-set_gyro-2) * 1.4
    servo_angle = constrain(servo_angle, -45, 45)
    servo.angle(-servo_angle)
Motor.DC(0)
servo.angle(-80)
time.sleep(0.5)
while abs(gyro) > 5:
    Motor.DC(-37)
servo.angle(0)
Motor.DC(10)
time.sleep(0.5)
Motor.DC(0)
Motor.DC(30)
while front_1 > 0.12:
    servo_angle = gyro * 1.4
    servo_angle = constrain(servo_angle, -45, 45)
    servo.angle(servo_angle)

# 停止伺服馬達與直流馬達，停止程式運行
servo.angle(0)         # 伺服馬達歸零角度停止轉動
Motor.DC(0)            # 直流馬達停止運轉
program_active = False # 結束主迴圈與各執行緒
imcap.stop()           # 停止攝影機影像擷取
cv2.destroyAllWindows()# 關閉所有OpenCV視窗

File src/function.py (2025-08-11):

# === 導入所需函式庫 ===
# 匯入GPIO控制(pigpio)、時間處理(time)、I2C通訊(smbus)、二進位資料處理(struct)、ROS雷射掃描訊息(sensor_msgs.msg.LaserScan)、ROS節點管理(rospy)、數學運算(math)模組
import pigpio
import time
import smbus
import struct
from sensor_msgs.msg import LaserScan
import rospy
import math

# === 硬體腳位設定與伺服角度校正參數 ===
Red_LED_pin = 17      # 紅色LED控制腳位
Green_LED_pin = 27    # 綠色LED控制腳位
Motor_IN1_pin = 10    # 直流馬達控制腳位IN1
Motor_IN2_pin = 22    # 直流馬達控制腳位IN2
Motor_PWM_pin = 5     # 直流馬達PWM調速腳位
Button_pin = 4        # 按鈕輸入腳位
Servo_pin = 21        # 伺服馬達控制腳位
offset = 43           # 伺服馬達角度校正值，用於調整伺服位置，確保伺服轉向中立（中間）位置

# 建立 pigpio 介面物件，用於控制 Raspberry Pi 的 GPIO
pi = pigpio.pi()

def mapping(x, in_min, in_max, out_min, out_max):
    # 將 x 從輸入範圍 [in_min, in_max] 線性映射到輸出範圍 [out_min, out_max]
    return (x - in_min) * (out_max - out_min) / (in_max - in_min) + out_min

def constrain(x, out_min, out_max):
    """
    限制數值 x 在指定範圍內（out_min 到 out_max）。
    若 x 小於下限，回傳下限；若大於上限，回傳上限；否則回傳原值。
    """
    return out_min if x < out_min else out_max if x > out_max else x

# 取得I2C總線
bus = smbus.SMBus(1)

# 裝置的I2C位址
TCS34725_DEFAULT_ADDRESS = 0x29

# TCS34725 Register Set
TCS34725_COMMAND_BIT = 0x80
TCS34725_REG_ENABLE = 0x00 # Enables states and interrupts
TCS34725_REG_ATIME = 0x01 # RGBC integration time
TCS34725_REG_WTIME = 0x03 # Wait time
TCS34725_REG_CONFIG = 0x0D # Configuration register
TCS34725_REG_CONTROL = 0x0F # Control register
TCS34725_REG_CDATAL = 0x14 # Clear/IR channel low data register
TCS34725_REG_CDATAH = 0x15 # Clear/IR channel high data register
TCS34725_REG_RDATAL = 0x16 # Red ADC low data register
TCS34725_REG_RDATAH = 0x17 # Red ADC high data register
TCS34725_REG_GDATAL = 0x18 # Green ADC low data register
TCS34725_REG_GDATAH = 0x19 # Green ADC high data register
TCS34725_REG_BDATAL = 0x1A # Blue ADC low data register
TCS34725_REG_BDATAH = 0x1B # Blue ADC high data register

# TCS34725 Enable Register Configuration
TCS34725_REG_ENABLE_SAI = 0x40 # Sleep After Interrupt
TCS34725_REG_ENABLE_AIEN = 0x10 # ALS Interrupt Enable
TCS34725_REG_ENABLE_WEN = 0x08 # Wait Enable
TCS34725_REG_ENABLE_AEN = 0x02 # ADC Enable
TCS34725_REG_ENABLE_PON = 0x01 # Power ON

# TCS34725 Time Register Configuration
TCS34725_REG_ATIME_2_4 = 0xFF # Atime = 2.4 ms, Cycles = 1
TCS34725_REG_ATIME_24 = 0xF6 # Atime = 24 ms, Cycles = 10
TCS34725_REG_ATIME_101 = 0xDB # Atime = 101 ms, Cycles = 42
TCS34725_REG_ATIME_154 = 0xC0 # Atime = 154 ms, Cycles = 64
TCS34725_REG_ATIME_700 = 0x00 # Atime = 700 ms, Cycles = 256
TCS34725_REG_WTIME_2_4 = 0xFF # Wtime = 2.4 ms
TCS34725_REG_WTIME_204 = 0xAB # Wtime = 204 ms
TCS34725_REG_WTIME_614 = 0x00 # Wtime = 614 ms

# TCS34725 Gain Configuration
TCS34725_REG_CONTROL_AGAIN_1 = 0x00 # 1x Gain
TCS34725_REG_CONTROL_AGAIN_4 = 0x01 # 4x Gain
TCS34725_REG_CONTROL_AGAIN_16 = 0x02 # 16x Gain
TCS34725_REG_CONTROL_AGAIN_60 = 0x03 # 60x Gain

class TCS34725():
    def __init__(self):
        self.enable_selection()
        self.time_selection()
        self.gain_selection()

    def enable_selection(self):
        """Select the ENABLE register configuration from the given provided values"""
        ENABLE_CONFIGURATION = (TCS34725_REG_ENABLE_AEN | TCS34725_REG_ENABLE_PON)
        bus.write_byte_data(TCS34725_DEFAULT_ADDRESS, TCS34725_REG_ENABLE | TCS34725_COMMAND_BIT, ENABLE_CONFIGURATION)

    def time_selection(self):
        """Select the ATIME register configuration from the given provided values"""
        bus.write_byte_data(TCS34725_DEFAULT_ADDRESS, TCS34725_REG_ATIME | TCS34725_COMMAND_BIT, TCS34725_REG_ATIME_2_4)

        """Select the WTIME register configuration from the given provided values"""
        bus.write_byte_data(TCS34725_DEFAULT_ADDRESS, TCS34725_REG_WTIME | TCS34725_COMMAND_BIT, TCS34725_REG_WTIME_2_4)

    def gain_selection(self):
        """Select the gain register configuration from the given provided values"""
        bus.write_byte_data(TCS34725_DEFAULT_ADDRESS, TCS34725_REG_CONTROL | TCS34725_COMMAND_BIT, TCS34725_REG_CONTROL_AGAIN_1)

    def readluminance(self):
        """Read data back from TCS34725_REG_CDATAL(0x94), 8 bytes, with TCS34725_COMMAND_BIT, (0x80)
        cData LSB, cData MSB, Red LSB, Red MSB, Green LSB, Green MSB, Blue LSB, Blue MSB"""
        data = bus.read_i2c_block_data(TCS34725_DEFAULT_ADDRESS, TCS34725_REG_CDATAL | TCS34725_COMMAND_BIT, 8)

        # Convert the data
        cData = data[1] * 256 + data[0]
        red = data[3] * 256 + data[2]
        green = data[5] * 256 + data[4]
        blue = data[7] * 256 + data[6]

		# Calculate luminance
        luminance = (-0.32466 * red) + (1.57837 * green) + (-0.73191 * blue)

        return {'c' : cData, 'r' : red, 'g' : green, 'b' : blue, 'l' : luminance}

class external_control():
    def __init__(self):
        # 設定紅色LED腳位為輸出模式
        pi.set_mode(Red_LED_pin, pigpio.OUTPUT)
        # 設定綠色LED腳位為輸出模式
        pi.set_mode(Green_LED_pin, pigpio.OUTPUT)
        # 設定按鈕腳位為輸入模式
        pi.set_mode(Button_pin, pigpio.INPUT)
        # 啟用按鈕腳位的上拉電阻，避免腳位懸空雜訊
        pi.set_pull_up_down(Button_pin, pigpio.PUD_UP)
    def button_read(self):
        # 讀取按鈕狀態，按下時返回低電位(0)，未按下返回高電位(1)
        return pi.read(Button_pin)
    def Green_OFF(self):
        # 關閉綠色LED
        pi.write(Green_LED_pin, pigpio.LOW)
    def Green_ON(self):
        # 開啟綠色LED
        pi.write(Green_LED_pin, pigpio.HIGH)
    def Red_OFF(self):
        # 關閉紅色LED
        pi.write(Red_LED_pin, pigpio.LOW)
    def Red_ON(self):
        # 開啟紅色LED
        pi.write(Red_LED_pin, pigpio.HIGH)


class dc_motor():
    def __init__(self):
        # 設定直流馬達控制腳位為輸出模式
        pi.set_mode(Motor_IN1_pin, pigpio.OUTPUT)
        pi.set_mode(Motor_IN2_pin, pigpio.OUTPUT)
        pi.set_mode(Motor_PWM_pin, pigpio.OUTPUT)
        
    def DC(self, power):
        """
        控制直流馬達轉動方向與速度
        power: 馬達動力大小，範圍 -100 到 100，正值正轉，負值反轉，0為停止
        """
        if power == 0:
            # 馬達停止，IN1與IN2都設低電位，PWM輸出為0
            pi.write(Motor_IN1_pin, pigpio.LOW)
            pi.write(Motor_IN2_pin, pigpio.LOW)
            pi.set_PWM_dutycycle(Motor_PWM_pin, 0)
        elif power > 0:
            # 馬達正轉，IN1設高，IN2設低，PWM根據power比例設定
            pi.write(Motor_IN1_pin, pigpio.HIGH)
            pi.write(Motor_IN2_pin, pigpio.LOW)
            # power值映射到0~255的PWM佔空比並限制範圍
            pi.set_PWM_dutycycle(Motor_PWM_pin, constrain(mapping(power, 0, 100, 0, 255), 0, 255))
        else:
            # 馬達反轉，IN1設低，IN2設高，PWM根據power絕對值比例設定
            pi.write(Motor_IN1_pin, pigpio.LOW)
            pi.write(Motor_IN2_pin, pigpio.HIGH)
            pi.set_PWM_dutycycle(Motor_PWM_pin, constrain(mapping(abs(power), 0, 100, 0, 255), 0, 255))
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

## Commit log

2025-06-29 底盤製作與材料選擇
2025-07-10 電源系統設計
2025-07-11 Upload 2D/3D Files
    [Bearing Holder_1.STL, Game Feiled Wall Holder - Inside.STL, Game Feiled Wall Holder - Outside.STL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]
2025-07-16 Create temp
    [12-0024.SLDPRT, 3S Battery.SLDPRT, Bearing Holder_1.SLDPRT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]
